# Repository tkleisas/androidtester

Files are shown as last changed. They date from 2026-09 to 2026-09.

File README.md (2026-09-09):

# AndroidTester

An **open-hardware robot that physically tests Android phones and tablets**. A
gantry places the device on a fixture and executes automated scenarios against
it with **real touch and real buttons** — the inputs a user (or a certification
lab) produces, not the inputs a debug bridge injects.

Everything is 3D-printable mechanics, commodity open electronics (Raspberry Pi +
Klipper, the 3D-printer firmware), and a Python framework that turns YAML
scenarios into motion + vision actions.

## Why physical, when ADB exists?

ADB/UI Automator can drive an app, but they can't:

- inject a **capacitive touch event the touchscreen controller actually felt**
  (edge rejection, glove/wet-finger behavior, screen-protector sensitivity),
- press the **physical power/volume buttons**,
- verify behavior with the device in its shipping state.

**Everything is physical.** Input is a real finger and real button presses;
verification is the **camera** — OCR and image checks on the screen as a user
would see it. Fully black-box: works on production builds, no USB debugging, no
agent on the device. The acceptance rule: *a scenario must pass with the
device's USB port unplugged.*

## The machine

- **CoreXY gantry** (3D-printer kinematics) moves a toolhead over the deck.
- **Tool-Z elevator** adapts the tools to device thickness and button height.
- **Finger tool** with a conductive tip taps, swipes, and long-presses the
  touchscreen; small servo plungers in the nest press recessed side buttons.
- **Cameras** (overhead + toolhead) register the deck and read the screen:
  ArUco homography, perspective rectification, OCR.
- **Klipper on a Raspberry Pi** drives motion; the Python framework talks to it
  over Moonraker and never issues raw moves below a safety clearance plane.

The toolhead is modular by design — the finger is the first tool, not the
only one the deck can carry.

## Hardware

The machine is a published open-hardware design (M0):

- **[docs/01-mechanical.md](docs/01-mechanical.md)** — 2020 frame, CoreXY
  layout, tool-Z elevator, finger/button tools, device nest; rail-length and
  tap-force arithmetic.
- **[docs/02-electronics.md](docs/02-electronics.md)** — BTT SKR Pico
  (RP2040) + Raspberry Pi, full pin map, power budget, power-cut E-stop.
- **[docs/03-bom.md](docs/03-bom.md)** — complete BOM, ≈ €420.
- **[cad/openscad/](cad/openscad/)** — parametric printable parts
  (`00_config.scad` holds every shared dimension), STLs in `cad/stl/`,
  previews in `docs/img/` (regenerate with
  `cad/openscad/render_previews.ps1`).
- **[firmware/klipper/androidtester.cfg](firmware/klipper/androidtester.cfg)** —
  the Klipper machine config: CoreXY X/Y, tool-Z as a `manual_stepper`, three
  servos, and the macro contract below.

Key numbers: 400 × 300 mm deck (= X/Y travel), 60 mm tool-Z, 40 mm clearance
plane, 1.5–6 N tap force from the finger's spring, X rail 500 mm / Y 2×400 mm
/ Z 150 mm (travel + carriage + margins — the arithmetic is in the docs and
checked by `tests/test_design_package.py`).

## The framework

YAML scenarios become motion + vision steps with per-step timeouts, artifact
capture, and JSON/JUnit reports:

```yaml
# scenarios/smoke_wake_unlock.yaml (excerpt)
pre:
  - camera.calibrate: { rms_below_mm: 0.5 }  # ArUco deck markers -> px/deck-mm
steps:
  - button.press: { key: power }        # servo plunger on the side button
  - touch.swipe: { from: [50%, 90%], to: [50%, 20%] }
  - touch.enter_pin: { pin_env: DEVICE_PIN_1 }   # secrets from env, never the repo
  - screen.wait_for: { text: "Home", timeout_s: 10 }
```

- **Device profiles** (`devices/*.yaml`): device class (phone/tablet), screen
  polygon, physical-button map, launcher layout, per-model quirks. New device =
  new YAML, not new code.
- **Actions**: `camera.calibrate`, `touch.tap/swipe/long_press/enter_pin`,
  `button.press`, `screen.wait_for/assert_text/assert_image`.
- **Example scenarios**: `smoke_wake_unlock` (power on, swipe, PIN by touch,
  home screen by OCR), `app_regression` (golden-path tap flow with OCR
  assertions), `tablet_rotation` (landscape/portrait UI checks across
  orientations).

## Digital twin

[steropes](https://github.com/tkleisas/steropes) — a 3D physics-based digital
twin for robotic test hardware — is the development companion: the machine's
motion, cameras, and device screen are simulated so the framework and vision
pipeline run before (and without) hardware.

### Run against the Steropes twin

With a steropes checkout on the same machine, the whole framework runs
against the physics simulation with **zero code changes** — only a config.
Terminal 1 (from the steropes checkout):

```
python -m steropes.server --profile profiles/android_phone_v1.yaml --port 7125
```

Terminal 2 (from this repo):

```
DEVICE_PIN_1=1337 .venv/Scripts/python -m androidtester.scenario \
    scenarios/smoke_wake_unlock.yaml --config harness.twin.yaml
```

(`1337` is the simulated DUT's PIN from the twin's own profile — no real
secret involved.) This proves the unmodified framework — motion client,
Klipper macro contract, ArUco deck calibration, and OCR vision checks —
works against a physically simulated machine over real HTTP: every tap is
physics, every verification is a real camera frame. `harness.twin.yaml` is
the stock config with only the Moonraker URL and the overhead camera pointed
at the twin's MJPEG stream.

The same flow also runs as an env-gated integration test that spawns the
twin itself on an ephemeral port:

```
STEROPES_ROOT=/c/projects/steropes .venv/Scripts/python -m pytest tests/test_twin_integration.py
```

## Roadmap

- **M0 — Machine design package** ✅: parametric OpenSCAD parts
  (`cad/openscad/`, previews in `docs/img/`), full Klipper config for a BTT
  SKR Pico rig, electronics and BOM docs (≈ €420). See
  [Hardware](#hardware). Proof:
  ```
  .venv/Scripts/python -m pytest tests/test_design_package.py   # consistency
  powershell -ExecutionPolicy Bypass -File cad/openscad/render_previews.ps1
  ```
- **M1 — Framework** ✅: motion client (Moonraker HTTP + strict `wait_idle`),
  YAML scenario engine with JSON/JUnit reports, vision pipeline (rectification,
  pluggable OCR + template fallback), Klipper macro contract, example device
  profiles and scenarios. Proof:
  ```
  .venv/Scripts/python -m pytest                       # 55 tests
  .venv/Scripts/python -m androidtester.scenario \
      scenarios/smoke_wake_unlock.yaml --dry-run        # no hardware needed
  ```
- **M2 — Camera deck registration** ✅: ArUco markers on the deck, normalized-DLT
  px↔deck-mm homography with RMS gating, `camera.calibrate` scenario step,
  OpenCV + synthetic cameras, fraction-coordinate taps. Proof:
  ```
  .venv/Scripts/python -m pytest                       # 80 tests
  .venv/Scripts/python -m androidtester.calib --device example_phone
      # synthetic deck: per-marker detection + RMS, saves an annotated frame
  ```
- **M3 — Device nest + profiles**: adjustable clamps for phones through tablets,
  side-button pressers, first device YAMLs.
- **M4 — Twin parity** ✅: steropes serves a Moonraker-compatible HTTP API
  and camera streams in front of the physics sim; the unmodified framework
  passes `smoke_wake_unlock` against it. Proof: the two-terminal recipe in
  [Run against the Steropes twin](#run-against-the-steropes-twin) above, or
  ```
  STEROPES_ROOT=/c/projects/steropes .venv/Scripts/python -m pytest  # twin integration tests
  ```

## Status

M0, M1, M2, and M4 done: the machine design package (CAD, Klipper config,
electronics, BOM — see [Hardware](#hardware)), the framework (motion client,
scenario engine, vision pipeline, reports, Klipper macro contract), camera
deck registration (ArUco homography, synthetic camera, calibration CLI), and
twin parity (the unmodified framework passing `smoke_wake_unlock` against the
steropes physics sim over HTTP) are implemented and tested — run them with no
hardware via the proof commands in the roadmap. Next: M3 (device nest +
profiles on real hardware).

## License

[MIT](LICENSE) — do what you want, attribution appreciated.

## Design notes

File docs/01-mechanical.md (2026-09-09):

# 01 — Mechanical design

The machine is a CoreXY gantry over a **400 × 300 mm deck**, built from 2020
extrusion, MGN linear rails, and printed parts (`cad/openscad/`, all
parametric — every dimension lives in `00_config.scad`). A tool-Z elevator
raises/lowers the tools; a servo-deployed conductive finger does touch input;
two servo plungers in the nest press side buttons.

## Frame

Base frame 500 × 400 mm (2020 extrusion, printed 3-way `corner_bracket`s),
four 200 mm posts, two 400 mm side beams carrying the Y rails, one 500 mm
gantry beam carrying the X rail, one 400 mm camera post at the rear. The deck
plate (400 × 300 × 4 mm aluminium) bolts to the base frame with an M4 hole
grid for the nest hardware.

Cut plan (2020, in mm): 2×500 + 2×400 base, 4×200 posts, 2×400 side beams,
1×500 gantry beam, 1×400 camera post → **4.3 m total → buy 5× 1 m** (0.7 m
spare for jigs and mistakes).

## Motion layout

- **X/Y: CoreXY.** Two NEMA17s with GT2 20T pulleys (2.0 mm pitch × 20 teeth
  = **40.0 mm/rev** `rotation_distance`), belt routed around 6 idlers, both
  belt ends terminate in `belt_clamp` wedges on the `toolhead_plate`. X rides
  a single MGN12H rail on the gantry beam; the beam ends ride two MGN12H Y
  rails on the side beams.
- **Tool-Z: elevator.** NEMA17 + T8 lead screw (2 mm pitch × 4 starts =
  **8 mm/rev**), 5→8 mm coupler, MGN9H rail (150 mm) guiding the tool lift.
  Driven as a Klipper `manual_stepper` — no G-code path can move Z; only the
  macro contract touches it. Homes **up** against a microswitch at the top of
  travel, away from the deck.

### Rail lengths (the arithmetic)

Rail ≥ travel + carriage length + 2 × end margin (10 mm: endstop trigger +
belt/idler clearance at each end). Same numbers in `00_config.scad`, enforced
by `tests/test_design_package.py`:

| Axis | Travel | Carriage | Margins | Min rail | Stock rail |
|---|---|---|---|---|---|
| X | 400 | 45 (MGN12H) | 2×10 | **465** | **500** |
| Y | 300 | 45 (MGN12H) | 2×10 | **365** | **400** (×2) |
| Z | 60 | 40 (MGN9H)  | 2×10 | **120** | **150** |

Travels equal the deck size (`position_max` in the cfg == `deck_width_mm` /
`deck_height_mm` in `androidtester/config.py`), so the finger reaches every
deck point including the ArUco corner markers.

## Tools

- **Finger** (`finger_module.scad`): a spring-loaded plunger in a printed
  body — Ø8 mm conductive stylus tip (M3 grub screw), Ø6 mm shaft in a guide
  bore, Ø8 × 25 mm compression spring in a top pocket retained by the
  toolhead plate. A deploy servo (`finger_deploy`, MG90S) swings the body
  between stow (clear of the nest) and working (vertical) positions.
- **Button plungers** (`button_plunger.scad`): two nest-mounted MG90S servos
  (`plunger_0`, `plunger_1`) driving Ø6 mm pins through guide bores into the
  device's side buttons. Slotted bases give 10 mm of edge-distance adjustment
  on the deck grid.

### Tap force budget

Target contact force: **1.5–6 N** (below the force that slides a device in
rubber-padded stops, above the touchscreen's registration threshold).

The Z axis does not control force — the **spring** does. Spring rate
k ≈ 0.5 N/mm (Ø8 × 25 mm compression spring, typical assortment value). The
framework sets `touch_z` so the tip meets the glass with the spring already
compressed ~3 mm:

- 3 mm compression → 1.5 N (light tap)
- up to 12 mm → 6 N (firm press / worn screen protector)

Z positioning resolution (8 mm/rev ÷ 200 full steps ÷ 16 µsteps =
**2.5 µm/µstep**) sets the compression to within 0.05 mm (≈0.03 N) — well
below the ~0.1 N system repeatability from homing and spring tolerances. The
15 mm plunger stroke absorbs device-thickness tolerance; the servo stow keeps
the tip off the deck during device swaps.

## Device nest

`device_nest.scad`: two fixed `corner_stop` L-references + two sliding
`side_clamp`s (30 mm slots, M5 thumb tabs) on the deck's M4 grid. Holds
devices from phones to ~11" tablets (≤ 280 × 200 mm). All nest hardware is
≤ 8 mm tall — below the screen, out of the overhead camera's view of the
glass, and outside the 40 mm ArUco keep-out zones at the deck corners
(`NEST_CLEAR`; markers sit one marker-width, 20 mm, in from each corner — see
`config.py deck_marker_map`).

## Cameras

- **Overhead**: USB webcam on the 400 mm rear post (`overhead_clamp`). A
  ~60°-FoV webcam at 400 mm covers ~460 mm across — the full 400 mm deck with
  margin. Used for ArUco deck registration and screen OCR.
- **Toolhead**: USB webcam under the gantry plate (`toolcam_bracket`), for
  close-up verification of taps and button states.

## Printed parts

| File | Parts | Notes |
|---|---|---|
| `frame_brackets.scad` | corner_bracket, motor_plate, idler_mount | ×4 corners, ×3 motor (X/Y/tool-Z), ×6 idler |
| `gantry_carriage.scad` | toolhead_plate, belt_clamp | plate ×1, clamp ×2 |
| `finger_module.scad` | finger_body, deploy_arm | |
| `button_plunger.scad` | plunger_base, plunger_pin | ×2 of each |
| `device_nest.scad` | corner_stop, side_clamp | ×2 of each |
| `camera_mounts.scad` | overhead_clamp, toolcam_bracket | |

Print in PETG, 4 perimeters, 40% infill. Previews in `docs/img/`, STLs in
`cad/stl/` — regenerate both with
`powershell -ExecutionPolicy Bypass -File cad/openscad/render_previews.ps1`.

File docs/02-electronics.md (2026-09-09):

# 02 — Electronics

## Controller: BIGTREETECH SKR Pico v1.0

Choice: **SKR Pico (RP2040)** running Klipper, hosted by a Raspberry Pi over
USB. Rationale:

- 4 TMC driver sockets for a machine that needs exactly **3 steppers**
  (CoreXY A/B + tool-Z) — no wasted board, no external drivers.
- Native Klipper support, RP2040 PWM on any GPIO (needed for 3 servos).
- Cheap (~€35), widely stocked, fully documented pinout; the Voron 0
  ecosystem proves the pin map.
- 24 V in, on-board 5 V — though we still power the Pi separately (see
  E-stop below).

The Raspberry Pi (4B, 2 GB) runs Klipper/Moonraker + the Python framework
and talks to the Pico over USB (`/dev/serial/by-id/...`, set in
`firmware/klipper/androidtester.cfg`).

## Pin map (matches `androidtester.cfg` exactly)

| Function | Pins | SKR Pico port |
|---|---|---|
| X step / dir / en | gpio11 / gpio10 / !gpio12 | X driver socket |
| X endstop | ^gpio4 | X-STOP |
| Y step / dir / en | gpio6 / gpio5 / !gpio7 | Y driver socket |
| Y endstop | ^gpio3 | Y-STOP |
| tool-Z step / dir / en | gpio19 / gpio28 / !gpio2 | Z driver socket |
| tool-Z endstop (top) | ^gpio25 | Z-STOP |
| TMC2209 UART (all) | gpio9 RX / gpio8 TX | shared; addresses X=0, Z=1, Y=2 (socket MS jumpers) |
| plunger_0 servo | gpio29 | SERVO port |
| plunger_1 servo | gpio14 | E0 socket STEP pin |
| finger_deploy servo | gpio13 | E0 socket DIR pin |
| placeholder stepper_z | gpio16 / gpio22 / !gpio15, endstop ^gpio26 | FSC / PROBE / E0-EN / THB — **nothing attached** |

Two notes:

- **E0 socket stays empty.** The machine has no extruder; its STEP/DIR pins
  are repurposed as servo signals #2 and #3. Servo 5 V/GND comes from the
  servo buck (below), not from the board.
- **Placeholder `stepper_z`.** Klipper's `corexy` kinematics loads x/y/z
  rails unconditionally, so a dummy Z rail sits on free pins and is never
  homed or moved (`HOME_ALL` does `G28 X Y` only). The real tool elevator is
  `[manual_stepper tool_z]`, commanded exclusively via `MANUAL_STEPPER` from
  the macro contract — no G-code path can crash Z into the deck.

## Power budget

| Rail | Load | Worst case | Supply |
|---|---|---|---|
| 24 V motion | 2× CoreXY NEMA17 @0.8 A RMS ≈ 2×15 W + tool-Z ≈ 10 W + board logic ≈ 5 W | ≈ 45 W | Meanwell LRS-150-24 (150 W) — >3× headroom |
| 5 V servo rail | 3× MG90S, stall 0.7 A each | ≈ 2.1 A ≈ 11 W | LM2596 buck 5 V/3 A from 24 V |
| 5 V Pi | Pi 4B + 2 USB webcams | ≈ 15 W | official 5 V/3 A USB-C supply |

## E-stop: power-cut, not firmware

A **2-pole NC mushroom** sits in series with the 24 V feed:

- pole 1 → SKR Pico VIN (kills steppers and board),
- pole 2 → servo buck input (kills the servo rail).

Motion power dies even if Klipper hangs; the Pi and cameras stay alive on
their own supply so the framework can capture the post-mortem frame and
report cleanly. This is why the Pi is *not* powered from the Pico's GPIO 5 V.
`M112` remains as the software layer on top.

## Wiring notes

- Endstops: lever microswitches, COM→G, NC→signal, `^` pull-ups as in the
  cfg. X/Y switches at the min ends; tool-Z switch at the **top** (home up,
  away from the deck).
- TMC2209s: set the MS jumpers for UART addresses X=0, Z=1, Y=2; one shared
  UART (gpio9/gpio8). Start at the cfg currents (0.8 A X/Y, 0.6 A tool-Z).
- Servos: signal wires from gpio29 (SERVO port) and the E0 STEP/DIR pads;
  5 V/GND from the buck. **Common ground** between buck output and SKR Pico
  GND is mandatory (the buck input shares 24 V GND with the board, which
  satisfies this).
- Toolhead loom (tool-Z motor, deploy servo, toolcam USB) in the 10×15 mm
  drag chain; leave USB-C camera leads strain-relieved at both ends.
- Bed/heater ports (gpio21/gpio23), fans (gpio17/18/20) and TH0 (gpio27) are
  unused; leave them unconfigured.

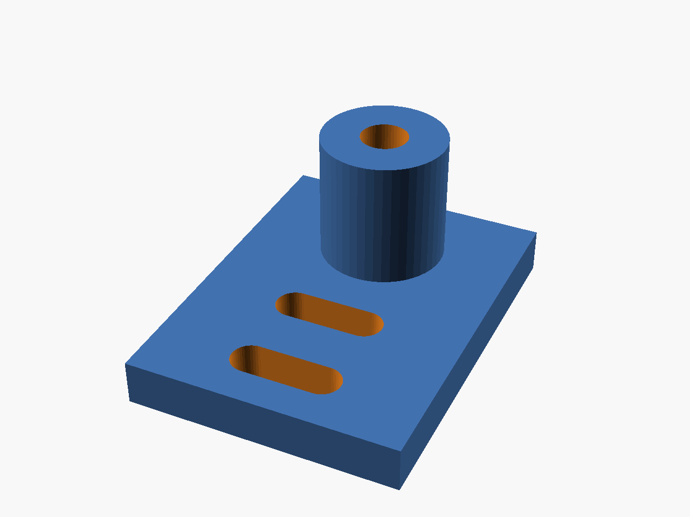
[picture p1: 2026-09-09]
docs/img/idler_mount.png

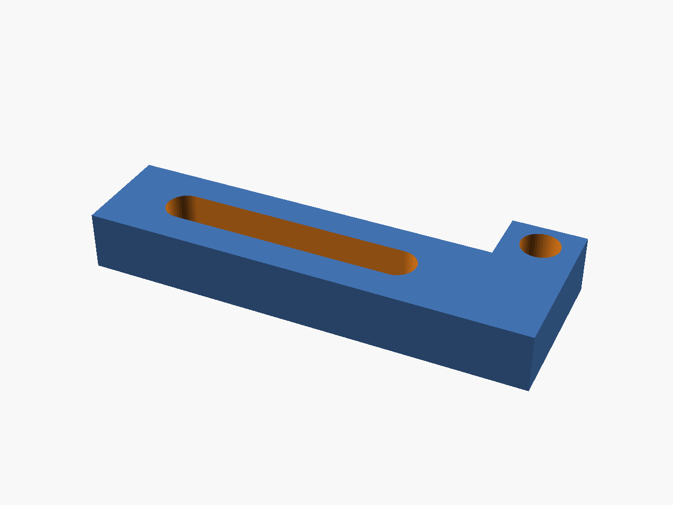
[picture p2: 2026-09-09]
docs/img/side_clamp.png

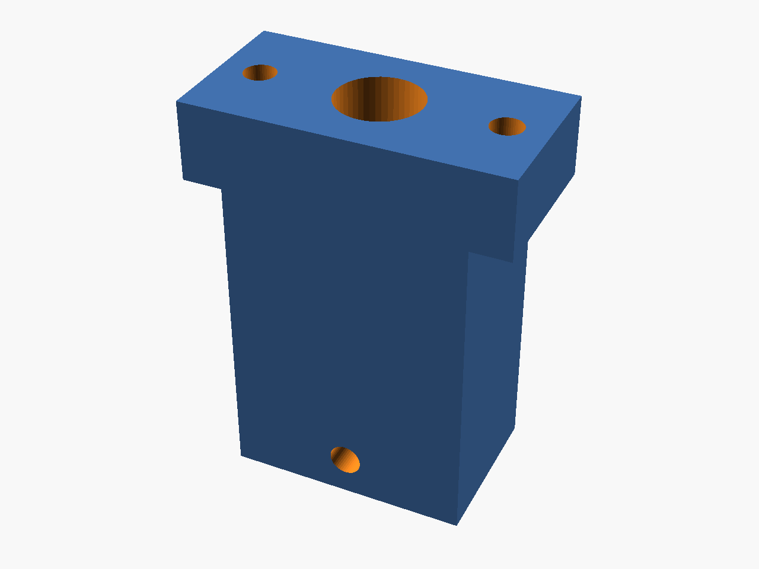
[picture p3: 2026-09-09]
docs/img/finger_body.png

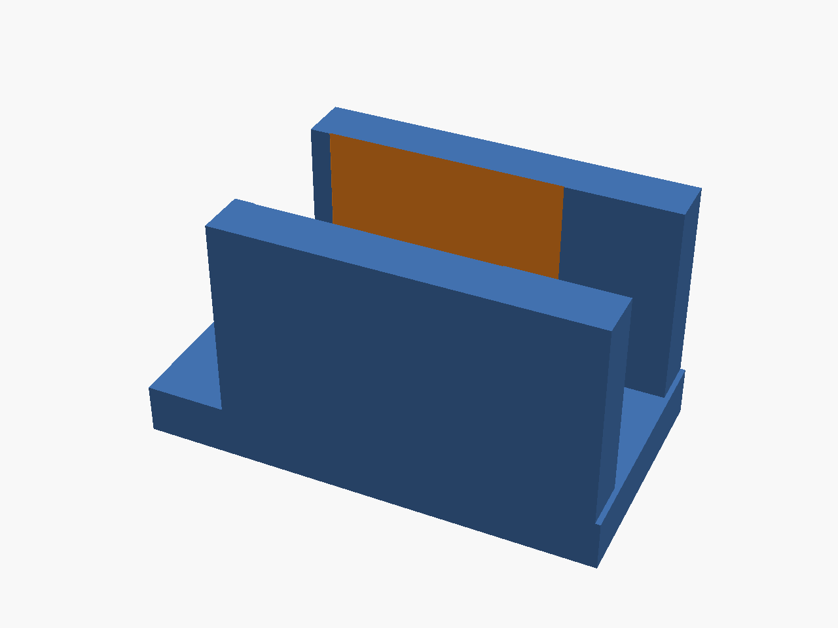
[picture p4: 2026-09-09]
docs/img/plunger_base.png

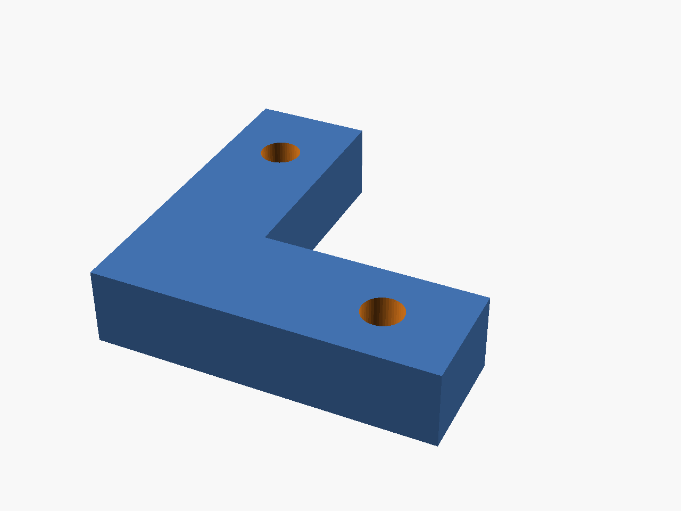
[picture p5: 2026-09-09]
docs/img/corner_stop.png

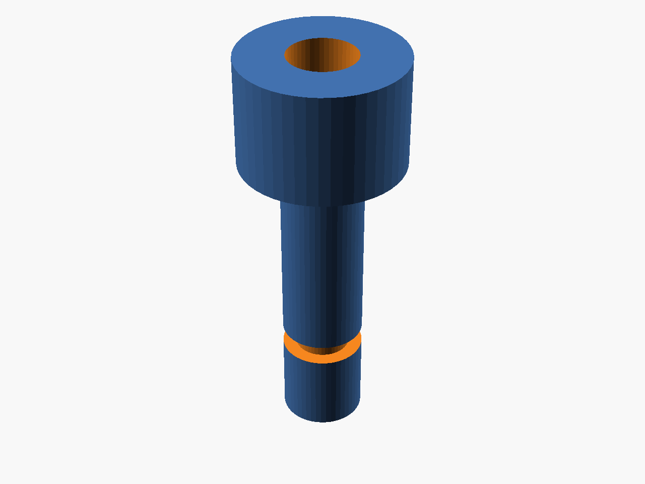
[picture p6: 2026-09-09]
docs/img/plunger_pin.png

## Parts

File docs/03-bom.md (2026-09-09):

# 03 — Bill of materials

Rough 2025 street prices (EUR, EU shops/AliExpress average), quantities match
`docs/01-mechanical.md` and `docs/02-electronics.md`. The table's arithmetic
is checked by `tests/test_design_package.py` (per-row qty × unit = line, and
the rows sum to the stated total).

| # | Item | Spec / purpose | Qty | Unit € | Line € |
|---|---|---|-----|---|---|
| 1 | 2020 aluminium extrusion, 1 m | frame 500×400, posts, gantry beam, camera post (4.3 m cut plan) | 5 | 6.00 | 30.00 |
| 2 | 2020 corner bracket + T-nut/screw kit | frame joinery | 1 | 15.00 | 15.00 |
| 3 | MGN12H linear rail 500 mm + carriage | X axis (min 465: 400 travel + 45 carriage + 2×10 margin) | 1 | 18.00 | 18.00 |
| 4 | MGN12H linear rail 400 mm + carriage | Y axis pair (min 365) | 2 | 15.00 | 30.00 |
| 5 | MGN9H linear rail 150 mm + carriage | tool-Z (min 120) | 1 | 9.00 | 9.00 |
| 6 | NEMA17 stepper, 40 mm, 1.5 A | CoreXY A/B + tool-Z = 3 steppers | 3 | 12.00 | 36.00 |
| 7 | GT2 20T drive pulley, 5 mm bore | CoreXY A/B motors (tool-Z is lead-screw driven) | 2 | 1.50 | 3.00 |
| 8 | GT2 20T idler pulley, 5 mm bore | CoreXY belt returns | 6 | 1.50 | 9.00 |
| 9 | GT2 open belt, 6 mm, 5 m roll | CoreXY loop (~2 m) + spare | 1 | 8.00 | 8.00 |
| 10 | T8 lead screw, 8 mm lead, 150 mm + nut | tool-Z elevator (8 mm/rev) | 1 | 8.00 | 8.00 |
| 11 | Flexible shaft coupler 5→8 mm | tool-Z motor to lead screw | 1 | 3.00 | 3.00 |
| 12 | BIGTREETECH SKR Pico v1.0 | motion controller (RP2040, Klipper) | 1 | 35.00 | 35.00 |
| 13 | TMC2209 stepper driver | X, Y, tool-Z = 3 drivers | 3 | 6.00 | 18.00 |
| 14 | Raspberry Pi 4B, 2 GB | Klipper/Moonraker host + framework | 1 | 50.00 | 50.00 |
| 15 | microSD card 32 GB | Pi system | 1 | 8.00 | 8.00 |
| 16 | Endstop microswitch with lever | X-min, Y-min, tool-Z top | 3 | 1.00 | 3.00 |
| 17 | MG90S servo (metal gear) | plunger_0, plunger_1, finger_deploy | 3 | 4.00 | 12.00 |
| 18 | LM2596 buck module, 5 V/3 A | servo rail from 24 V | 1 | 3.00 | 3.00 |
| 19 | Meanwell LRS-150-24 PSU | 24 V motion + servo buck input | 1 | 25.00 | 25.00 |
| 20 | E-stop mushroom, 22 mm, 2-pole NC | power cut (motion + servo rails) | 1 | 6.00 | 6.00 |
| 21 | USB webcam 1080p | overhead + toolhead cameras | 2 | 12.00 | 24.00 |
| 22 | Conductive stylus tips, Ø8 mm | finger tool, consumable | 5 | 1.00 | 5.00 |
| 23 | Compression spring assortment, Ø8×25 | finger plunger, k ≈ 0.5 N/mm | 1 | 5.00 | 5.00 |
| 24 | Deck plate 400×300×4 mm, aluminium | M4 grid drilled for nest hardware | 1 | 12.00 | 12.00 |
| 25 | Wire/ferrule/JST-XH/Dupont kit | all cabling | 1 | 15.00 | 15.00 |
| 26 | PETG filament, ~0.5 kg | printed parts (0.4 kg estimated) | 1 | 10.00 | 10.00 |
| 27 | M3/M4/M5 bolt & nut kit | assembly | 1 | 10.00 | 10.00 |
| 28 | Cable drag chain 10×15 mm, 1 m | toolhead loom | 1 | 8.00 | 8.00 |

**Total: ≈ €418.00** (the exact sum of the Line € column; "≈" because unit
prices are rough). Not included: shipping, a USB-C cable for the Pi↔Pico
link, and the Android device under test.

## Sourcing notes

- Rails: "MGN12H" = the long carriage; vendor block-hole spacing varies
  (nominal M3 on 20×20 mm) — check the delivered blocks before bolting down
  `toolhead_plate`.
- Any SG90/MG90S-class 9 g servo fits the pockets; metal-gear MG90S survives
  plunger duty longer.
- The SKR Pico clones vary in TMC UART jumper labelling — the addresses
  (X=0, Z=1, Y=2) are what the cfg assumes; verify with `DUMP_TMC`.

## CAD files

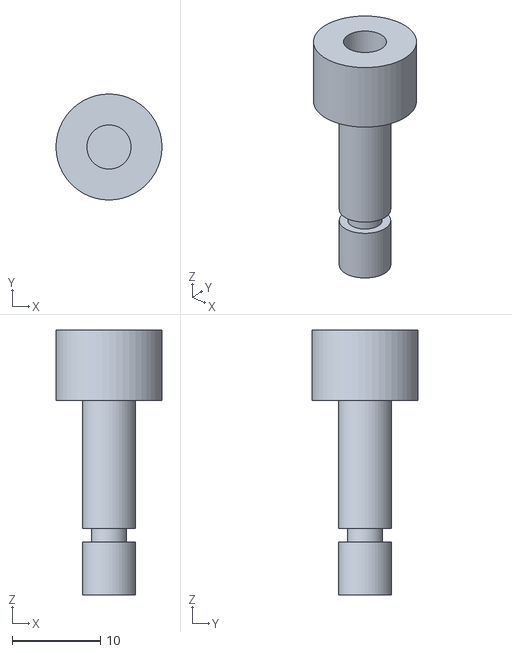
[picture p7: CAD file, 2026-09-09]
cad/stl/plunger_pin.stl
12.0 x 12.0 x 30.0

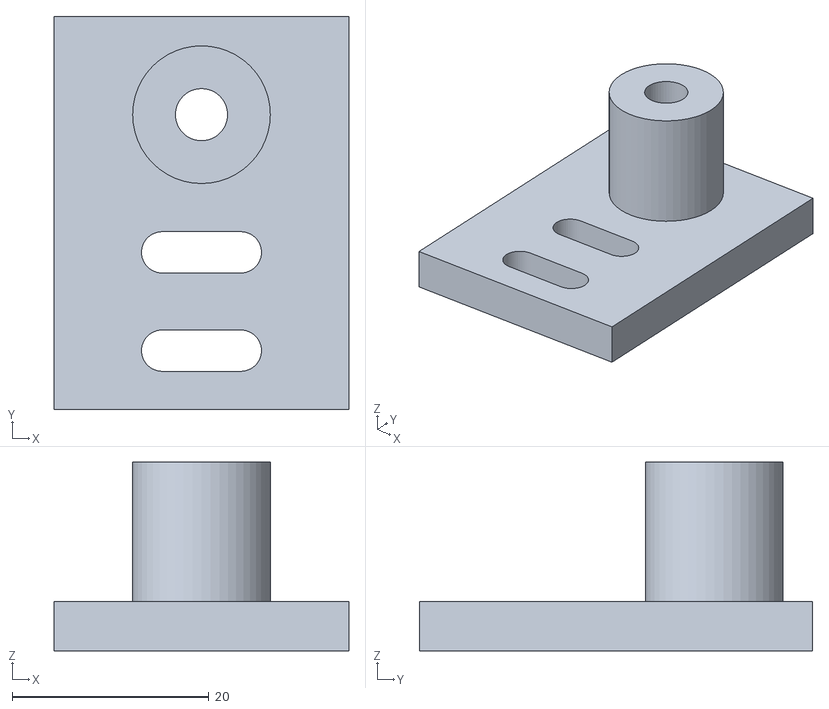
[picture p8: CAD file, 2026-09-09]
cad/stl/idler_mount.stl
30.0 x 40.0 x 19.2

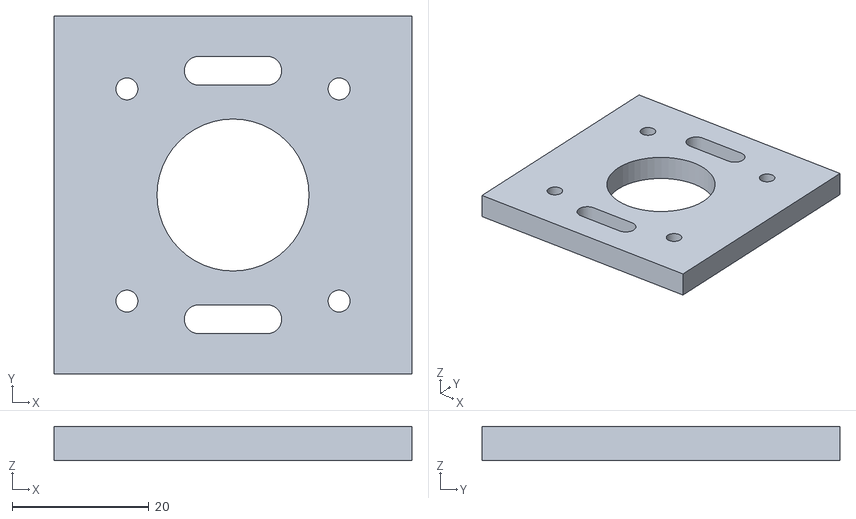
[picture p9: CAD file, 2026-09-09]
cad/stl/motor_plate.stl
52.3 x 52.3 x 5.00

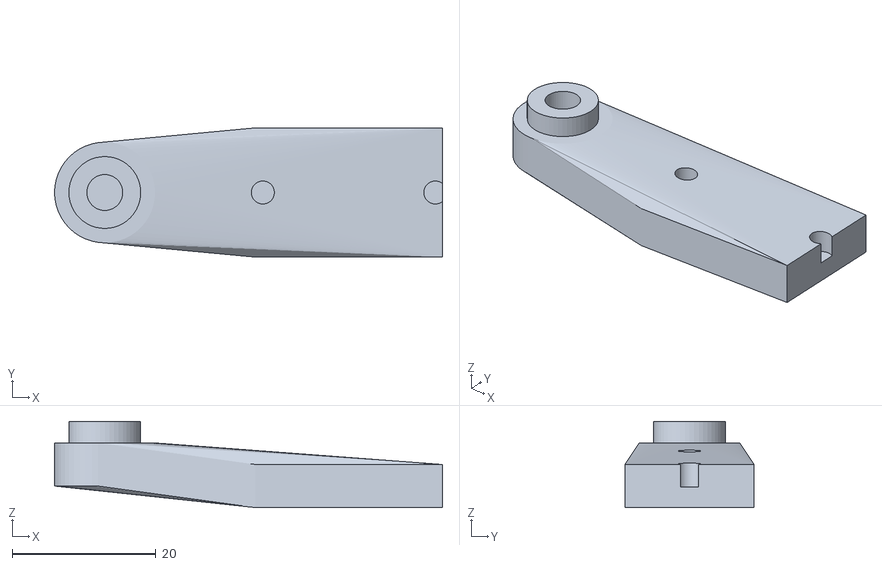
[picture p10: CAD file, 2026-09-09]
cad/stl/deploy_arm.stl
54.0 x 18.0 x 12.0

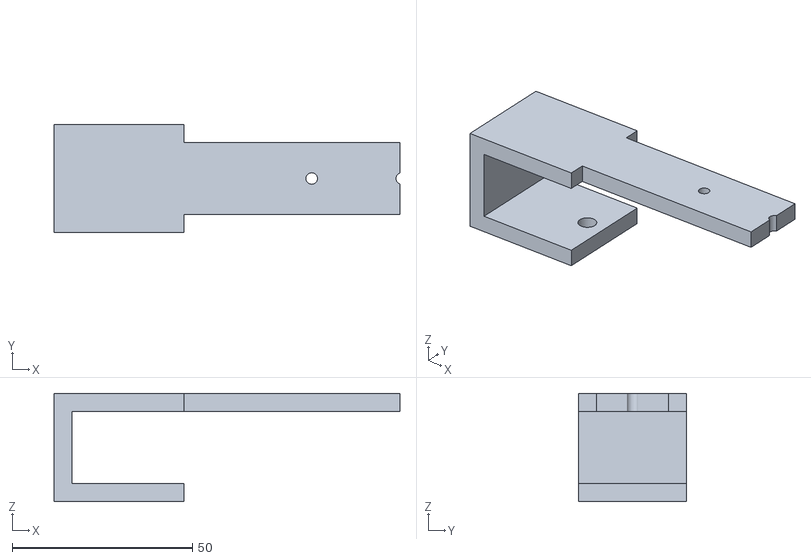
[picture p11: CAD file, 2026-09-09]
cad/stl/overhead_clamp.stl
96.0 x 30.0 x 30.0

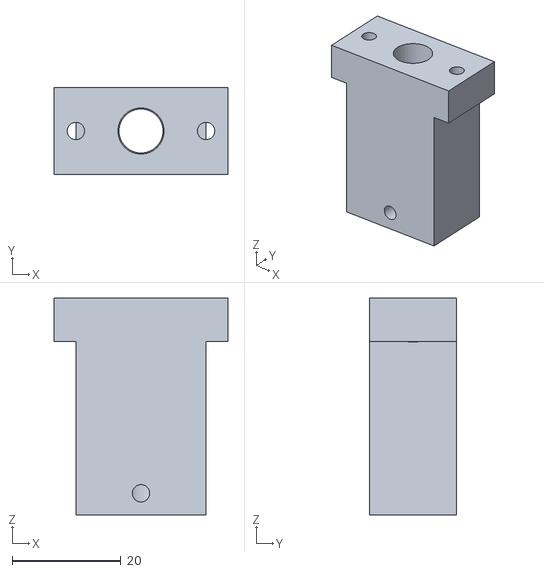
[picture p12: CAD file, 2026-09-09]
cad/stl/finger_body.stl
32.0 x 16.0 x 40.0

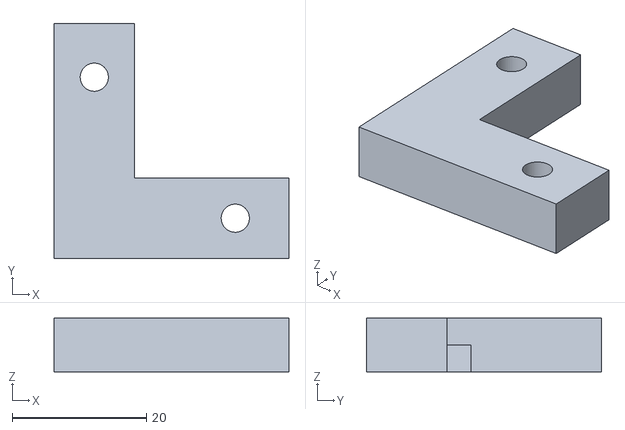
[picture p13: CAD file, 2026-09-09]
cad/stl/corner_stop.stl
35.0 x 35.0 x 8.00

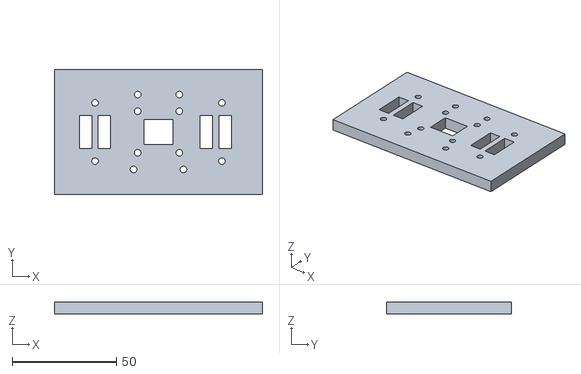
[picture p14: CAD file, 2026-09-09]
cad/stl/toolhead_plate.stl
100.0 x 60.0 x 6.00

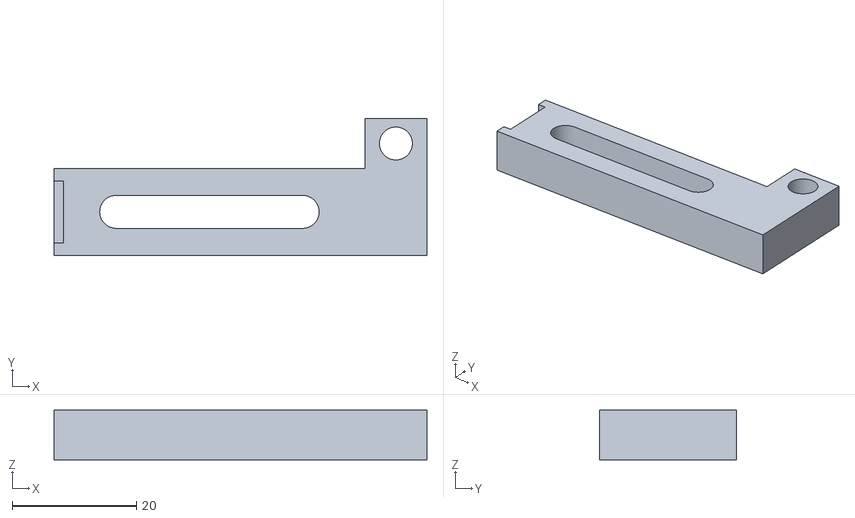
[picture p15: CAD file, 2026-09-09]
cad/stl/side_clamp.stl
60.0 x 22.0 x 8.00

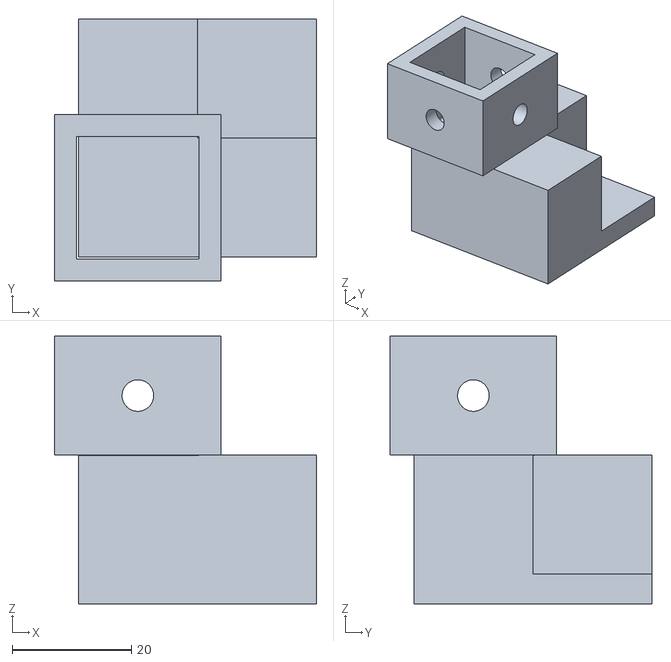
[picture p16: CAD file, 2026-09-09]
cad/stl/corner_bracket.stl
44.0 x 44.0 x 45.0

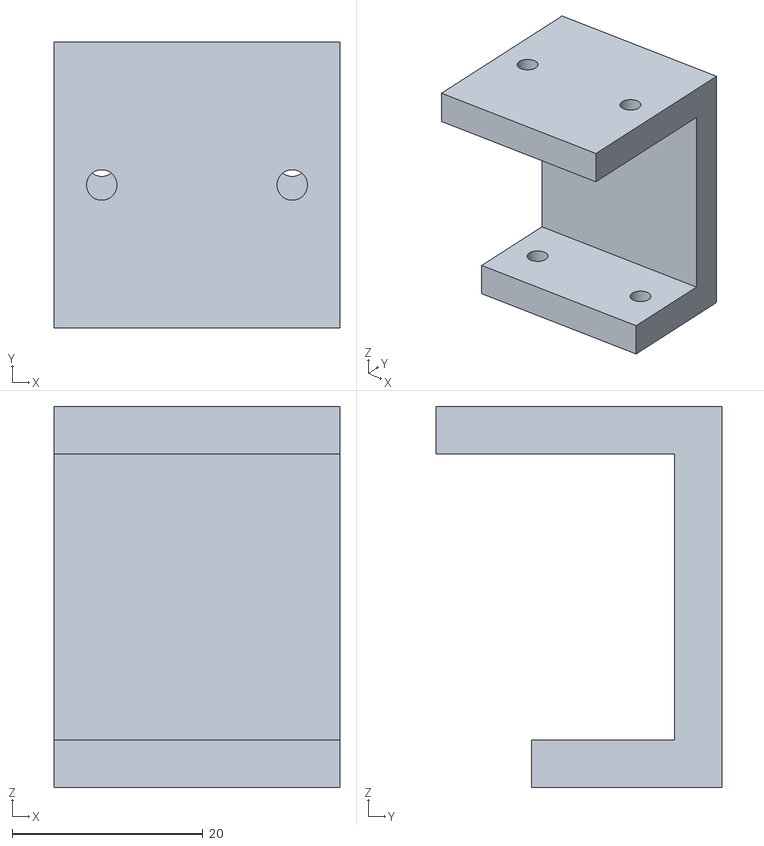
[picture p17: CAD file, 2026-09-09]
cad/stl/toolcam_bracket.stl
30.0 x 30.0 x 40.0

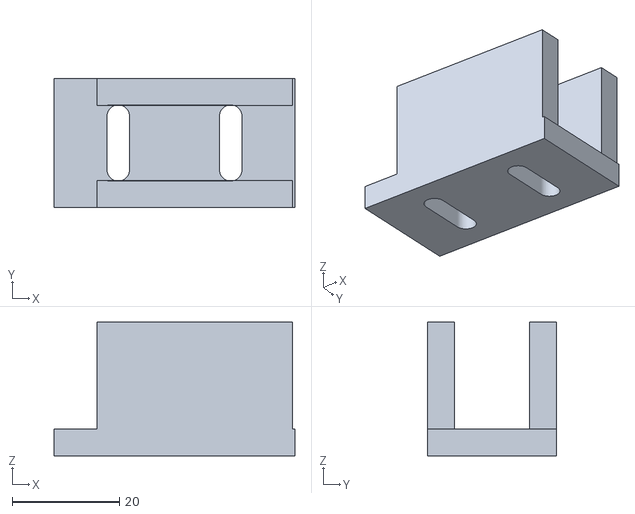
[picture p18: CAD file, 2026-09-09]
cad/stl/plunger_base.stl
45.0 x 24.0 x 25.0

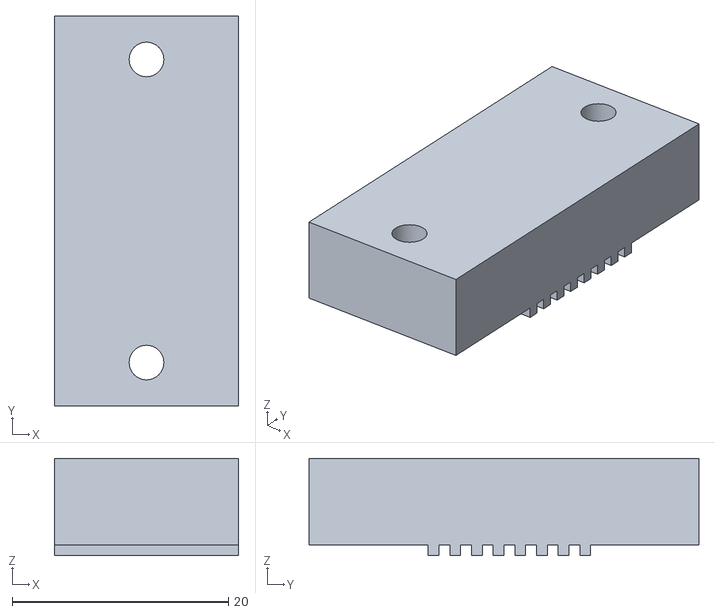
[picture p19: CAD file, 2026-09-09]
cad/stl/belt_clamp.stl
17.0 x 36.0 x 9.00

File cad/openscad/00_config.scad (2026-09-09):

// 00_config.scad — shared dimensions for the AndroidTester machine, in mm.
//
// These constants are the single source for every part in cad/openscad/.
// They are cross-checked by tests/test_design_package.py against
// androidtester/config.py (deck size, clearance planes) and
// firmware/klipper/androidtester.cfg (position_max) — change them together.

// -- deck and travels -------------------------------------------------------
// Deck == reachable XY (cfg position_max == config.py deck defaults).
DECK_W   = 400;          // deck X, config.py deck_width_mm, stepper_x position_max
DECK_D   = 300;          // deck Y, config.py deck_height_mm, stepper_y position_max
X_TRAVEL = 400;          // == DECK_W
Y_TRAVEL = 300;          // == DECK_D
Z_TRAVEL = 60;           // tool-Z elevator travel (manual_stepper tool_z)
TRAVEL_Z = 40;           // clearance plane, config.py travel_z_mm
TOUCH_Z  = 5;            // finger-tip contact plane, config.py touch_z_mm

// -- linear rails -------------------------------------------------------------
// X rail: must span the full X travel plus the carriage plus end margins:
//   X_TRAVEL (400) + X_CARRIAGE_LEN (45) + 2*END_MARGIN (10) = 465 mm min
//   -> RAIL_X_LEN = 500 (next stock MGN12 length, 35 mm of setup slack).
// Y rails (x2, carry the gantry beam):
//   Y_TRAVEL (300) + X_CARRIAGE_LEN (45) + 2*END_MARGIN (10) = 365 mm min
//   -> RAIL_Y_LEN = 400.
// Z rail (tool elevator, MGN9):
//   Z_TRAVEL (60) + Z_CARRIAGE_LEN (40) + 2*END_MARGIN (10) = 120 mm min
//   -> RAIL_Z_LEN = 150.
RAIL_X_LEN = 500;
RAIL_Y_LEN = 400;
RAIL_Z_LEN = 150;
X_CARRIAGE_LEN = 45;     // MGN12H block, 27 x 45.4 mm (nominal — verify rail vendor)
Z_CARRIAGE_LEN = 40;     // MGN9H block, 20 x 38.9 mm (nominal — verify rail vendor)
END_MARGIN   = 10;       // endstop trigger + belt/idler clearance at each rail end
RAIL12_W = 12;           // MGN12 rail width / height
RAIL12_H = 8;
RAIL9_W  = 9;            // MGN9 rail width / height
RAIL9_H  = 6.5;

// -- frame --------------------------------------------------------------------
EXT = 20;                // 2020 aluminium extrusion (6 mm slot)
FRAME_W = DECK_W + 100;  // 500 — gantry beam carries the full X rail (500)
FRAME_D = DECK_D + 100;  // 400 — side beams carry the full Y rails (400)
POST_H  = 200;           // gantry posts above the base frame
CAM_POST_H = 400;        // overhead camera post above the deck

// -- motors / motion hardware ---------------------------------------------------
NEMA_W   = 42.3;         // NEMA17 face
NEMA_HOLE_SP = 31;       // NEMA17 M3 hole spacing
NEMA_BORE  = 22.2;       // NEMA17 pilot bore (clearance)
PULLEY_D = 12.2;         // GT2 20T pulley OD (2 mm pitch x 20 T = 40 mm/rev)
IDLER_D  = 12.2;         // GT2 20T idler OD, 5 mm bore
BELT_W   = 6;            // GT2 belt width
LEAD_D   = 8;            // T8 lead screw (2 mm pitch x 4 starts = 8 mm/rev)

// -- servos (SG90 / MG90S class) -------------------------------------------------
SERVO_W   = 23;          // body across tabs axis
SERVO_D   = 12.5;        // body depth
SERVO_H   = 23;          // body height below the mounting tabs
SERVO_TAB_W = 32.5;      // across the mounting tabs
SERVO_SHAFT_D = 5;       // output shaft / horn boss clearance
SERVO_SHAFT_OFF = 6;     // shaft centre from body end wall

// -- finger tool -----------------------------------------------------------------
FINGER_TIP_D  = 8;       // conductive tip diameter
FINGER_SHAFT_D = 6;      // plunger shaft
SPRING_D  = 8.5;         // compression-spring pocket (Ø8 spring, k ≈ 0.5 N/mm)
FINGER_STROKE = 15;      // spring working stroke (3–12 mm compression -> 1.5–6 N)

// -- fasteners ---------------------------------------------------------------------
M3_CLEAR = 3.2;
M4_CLEAR = 4.2;
M5_CLEAR = 5.3;
M3_HEAD  = 6.0;          // M3 button-head clearance

// -- device nest ---------------------------------------------------------------------
DEVICE_MAX_W = 280;      // phones through ~11" tablets (250 x 170 + case)
DEVICE_MAX_D = 200;
NEST_STOP_H  = 8;        // stop height: below screen, clear of ArUco markers
NEST_CLEAR   = 40;       // keep-out at each deck corner (ArUco marker zone)

$fn = 48;

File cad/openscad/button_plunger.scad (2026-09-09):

// button_plunger.scad — nest-mounted servo plunger for recessed side buttons
// (power / volume). The servo body bolts to a slotted base on the deck plate;
// its horn carries a Ø6 push pin riding in a guide bore, aligned with the
// device edge. Two of these live on the nest (plunger_0 / plunger_1).
//
// Parts (PART selector):
//   plunger_base — servo cradle + deck slots (M4, 15 mm edge-distance travel)
//   plunger_pin  — push pin with horn hub and return-spring groove
//
// Export: openscad -o plunger_base.stl -D 'PART="plunger_base"' button_plunger.scad
include <00_config.scad>

PART = is_undef(_AT_PART) ? "preview" : _AT_PART;  // -D 'PART=...' or a render wrapper overrides

module plunger_base() {
    base_w = 45;
    base_d = 24;
    t = 5;
    cradle_h = 20;
    gap = base_d - 2 * t;   // 14 mm = SERVO_D (12.5) + running clearance
    difference() {
        union() {
            cube([base_w, base_d, t]);
            // cradle walls: servo body drops between them, tabs rest on top
            for (sy = [0, base_d - t])
                translate([8, sy, t]) cube([SERVO_TAB_W + 4, t, cradle_h]);
        }
        // servo well between the walls, open at the top (tabs sit on the walls)
        translate([8 + 2, t - 0.1, t + 4])
            cube([SERVO_W + 0.4, gap + 0.2, cradle_h]);
        // pin guide bore Ø6.2 through both walls at horn height
        translate([8 - 0.1, base_d / 2, t + 12])
            rotate([0, 90, 0]) cylinder(d = 6.2, h = SERVO_TAB_W + 4.2);
        // M4 deck slots, 10 mm of edge-distance adjustment
        for (x = [12, base_w - 12])
            hull()
                for (dy = [-5, 5])
                    translate([x, base_d / 2 + dy, -0.1])
                        cylinder(d = M4_CLEAR, h = t + 0.2);
    }
}

module plunger_pin() {
    pin_l = 30;
    difference() {
        union() {
            cylinder(d = 6, h = pin_l);                       // push pin
            translate([0, 0, pin_l - 8]) cylinder(d = 12, h = 8); // horn hub
        }
        // horn boss bore + M3 screw
        translate([0, 0, pin_l - 8.1]) cylinder(d = SERVO_SHAFT_D, h = 8.2);
        // return-spring groove (Ø1 wire, 2 mm deep, 6 mm from the tip)
        translate([0, 0, 6]) rotate_extrude()
            translate([2, 0, 0]) square([2, 1.5]);
    }
}

// -- preview / selector ---------------------------------------------------------
if (PART == "preview" || PART == "plunger_base")
    plunger_base();
if (PART == "preview")
    translate([55, 15, 0]) plunger_pin();
else if (PART == "plunger_pin")
    plunger_pin();

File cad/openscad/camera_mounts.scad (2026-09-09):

// camera_mounts.scad — machine-vision mounts.
//   overhead_clamp — clamps the rear 2020 post, holds the overhead webcam
//                    CAM_POST_H (400 mm) above the deck centre
//   toolcam_bracket — toolhead camera on the gantry plate's rear M3 pattern
//
// Export: openscad -o overhead_clamp.stl -D 'PART="overhead_clamp"' camera_mounts.scad
include <00_config.scad>

PART = is_undef(_AT_PART) ? "preview" : _AT_PART;  // -D 'PART=...' or a render wrapper overrides

module overhead_clamp() {
    w = EXT + 16;        // wraps the post with two 8 mm cheeks
    t = 5;
    arm = 60;            // camera arm toward the deck centre
    difference() {
        union() {
            // C-clamp around the 2020 post
            cube([w, EXT + 2 * t, t]);                  // jaw bottom
            translate([0, 0, t]) cube([t, EXT + 2 * t, EXT]); // spine
            translate([0, 0, t + EXT]) cube([w, EXT + 2 * t, t]); // jaw top
            // camera arm off the top jaw
            translate([w, t, t + EXT]) cube([arm, EXT, t]);
        }
        // M5 clamp screw pulling the jaws onto the post slots
        translate([w - 6, t + EXT / 2, -0.1]) cylinder(d = M5_CLEAR, h = t + 0.2);
        // webcam plate holes: 2 x M3 on 25 mm spacing at the arm end
        for (sx = [-1, 1])
            translate([w + arm - 12 + sx * 12.5, t + EXT / 2, t + EXT - 0.1])
                cylinder(d = M3_CLEAR, h = t + 0.2);
    }
}

module toolcam_bracket() {
    w = 30;
    t = 5;
    drop = 35;           // camera sits below the plate, lens past the finger
    difference() {
        union() {
            cube([w, w, t]);                             // flange to the plate
            translate([0, w - t, -drop]) cube([w, t, drop + t]); // vertical leg
            translate([0, w - t - 15, -drop]) cube([w, 15, t]); // camera shelf
        }
        // flange holes matching the toolhead plate rear pattern (20 mm)
        for (sx = [-1, 1])
            translate([w / 2 + sx * 10, w / 2, -0.1])
                cylinder(d = M3_CLEAR, h = t + 0.2);
        // camera M3 holes in the shelf
        for (sx = [-1, 1])
            translate([w / 2 + sx * 10, w - t - 7.5, -drop - 0.1])
                cylinder(d = M3_CLEAR, h = t + 0.2);
    }
}

// -- preview / selector ---------------------------------------------------------
if (PART == "preview" || PART == "overhead_clamp")
    overhead_clamp();
if (PART == "preview")
    translate([110, 0, 45]) toolcam_bracket();
else if (PART == "toolcam_bracket")
    toolcam_bracket();

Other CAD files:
cad/openscad/device_nest.scad
cad/openscad/finger_module.scad
cad/openscad/frame_brackets.scad
cad/openscad/gantry_carriage.scad

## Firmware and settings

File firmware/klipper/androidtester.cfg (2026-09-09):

# AndroidTester Klipper config — BIGTREETECH SKR Pico v1.0 (RP2040 over USB).
#
# CoreXY gantry (stepper_x/stepper_y) + tool-Z elevator as a manual_stepper
# (auxiliary axis, not part of the CoreXY kinematics) + three hobby servos
# (two nest button plungers, one finger deploy/stow). Design docs:
# docs/01-mechanical.md, docs/02-electronics.md (pin map, power, E-stop).
#
# This file defines the macro contract the Python framework calls (see
# androidtester/harness.py); tests/test_macro_contract.py fails if the two
# drift apart. Straight-line moves only, no math.* in templates (Klipper's
# Jinja context lacks it). Calibrate rotation_distance/endstop polarity on
# the real machine.
#
# Flash the RP2040 with USB communication; get the serial path from
# `ls /dev/serial/by-id/` after the first boot.

[mcu]
serial: /dev/serial/by-id/usb-Klipper_rp2040_CHANGE_ME
restart_method: command

[printer]
kinematics: corexy
max_velocity: 200
max_accel: 1500
# No max_z_velocity/max_z_accel: the real tool-Z is [manual_stepper tool_z]
# below; the placeholder Z rail never moves.

# Klipper's corexy kinematics loads three rails (x/y/z) unconditionally, so a
# placeholder stepper_z must exist even though this rig has no G-code Z axis.
# It sits on otherwise-unused pins (E0 enable, filament-sensor port, probe
# port, THB input), is NEVER homed (HOME_ALL does G28 X Y only) and never
# moved — the tool elevator is driven exclusively via MANUAL_STEPPER so no
# G-code path can move Z. Nothing is attached to these pins.
[stepper_z]
step_pin: gpio16                    # FSC port (free)
dir_pin: gpio22                     # PROBE port (free)
enable_pin: !gpio15                 # E0 socket EN (socket empty)
microsteps: 16
rotation_distance: 8
endstop_pin: ^gpio26                # THB input, usable as digital-in
position_min: 0
position_max: 60
position_endstop: 0
homing_speed: 5

# -- motion: CoreXY A/B ---------------------------------------------------------
# rotation_distance 40 = GT2 belt (2.0 mm pitch) x 20-tooth pulley = 40.0 mm/rev.

[stepper_x]
step_pin: gpio11
dir_pin: gpio10
enable_pin: !gpio12
microsteps: 16
rotation_distance: 40               # 2.0 mm pitch x 20 T pulley
endstop_pin: ^gpio4                 # X-STOP port, microswitch to GND
position_endstop: 0
position_max: 400                   # == config.py deck_width_mm
homing_speed: 40

[tmc2209 stepper_x]
uart_pin: gpio9
tx_pin: gpio8
uart_address: 0                     # MS jumper block: X socket = address 0
sense_resistor: 0.110
run_current: 0.8
stealthchop_threshold: 999999

[stepper_y]
step_pin: gpio6
dir_pin: gpio5
enable_pin: !gpio7
microsteps: 16
rotation_distance: 40               # 2.0 mm pitch x 20 T pulley
endstop_pin: ^gpio3                 # Y-STOP port, microswitch to GND
position_endstop: 0
position_max: 300                   # == config.py deck_height_mm
homing_speed: 40

[tmc2209 stepper_y]
uart_pin: gpio9
tx_pin: gpio8
uart_address: 2                     # MS jumper block: Y socket = address 2
sense_resistor: 0.110
run_current: 0.8
stealthchop_threshold: 999999

# -- tool-Z elevator (finger height) --------------------------------------------
# NEMA17 + T8 lead screw: rotation_distance 8 = 2 mm pitch x 4 starts = 8 mm/rev.
# Homes UP against a microswitch at the top of travel (away from the deck) via
# MANUAL_STEPPER ... STOP_ON_ENDSTOP=home, then SET_POSITION fixes the frame.
# NOTE: no position_min/position_max here on purpose — the homing move targets
# past the switch and would be range-rejected. The macros only ever command
# 0..Z_TOP.

[manual_stepper tool_z]
step_pin: gpio19
dir_pin: gpio28
enable_pin: !gpio2
microsteps: 16
rotation_distance: 8                # T8x8 lead screw
velocity: 30
accel: 200
endstop_pin: ^gpio25                # Z-STOP port, switch at the TOP of travel

[tmc2209 manual_stepper tool_z]
uart_pin: gpio9
tx_pin: gpio8
uart_address: 1                     # MS jumper block: Z socket = address 1
sense_resistor: 0.110
run_current: 0.6                    # lead screw only lifts the ~150 g tool
stealthchop_threshold: 999999

# -- servos ----------------------------------------------------------------------
# plunger_0/plunger_1 are the contract names devices/*.yaml map buttons to.
# finger_deploy swings the finger tool between stow and working positions.
# The E0 driver socket stays EMPTY: its STEP/DIR pins are repurposed as the
# two extra servo signals (RP2040 PWM works on any GPIO). Servo 5 V/GND comes
# from the servo buck, not the board — see docs/02-electronics.md.

[servo plunger_0]                   # e.g. power button
pin: gpio29                         # SERVO port
maximum_servo_angle: 180
minimum_pulse_width: 0.0005
maximum_pulse_width: 0.0025

[servo plunger_1]                   # e.g. volume buttons
pin: gpio14                         # E0 socket STEP pin (socket unused)
maximum_servo_angle: 180
minimum_pulse_width: 0.0005
maximum_pulse_width: 0.0025

[servo finger_deploy]               # finger tool stow/deploy
pin: gpio13                         # E0 socket DIR pin (socket unused)
maximum_servo_angle: 180
minimum_pulse_width: 0.0005
maximum_pulse_width: 0.0025

# -- machine constants (calibrate per rig) --------------------------------------
# travel_z/touch_z mirror config.py travel_z_mm/touch_z_mm (checked by
# tests/test_design_package.py).

[gcode_macro _AT_VARS]
description: AndroidTester machine constants
variable_travel_z: 40.0           # clearance plane: no XY travel below this
variable_touch_z: 5.0             # finger-tip contact height
variable_z_top: 60.0              # tool-Z travel limit (top endstop position)
variable_park_x: 10.0
variable_park_y: 10.0
variable_travel_speed: 150.0      # mm/s (XY)
variable_z_speed: 30.0            # mm/s (tool-Z)
variable_z_touch_speed: 10.0      # mm/s (tool-Z approach to the glass)
variable_plunger_rest_angle: 10
variable_plunger_press_angle: 80
variable_finger_deploy_angle: 90  # working position (finger vertical)
variable_finger_stow_angle: 0     # swung clear of the nest
gcode:                            # variables only; never called directly

# -- macro contract: called by androidtester/harness.py --------------------------
# Every FINGER_* macro returns tool-Z to travel_z; HOME_ALL re-zeros the frame,
# so the absolute MANUAL_STEPPER moves below never drift.

[gcode_macro HOME_ALL]
description: Home X, Y, and tool-Z
gcode:
    {% set v = printer["gcode_macro _AT_VARS"] %}
    G90
    G28 X Y
    # tool-Z: drive past the top switch, stop on trigger, then define position
    MANUAL_STEPPER STEPPER=tool_z SET_POSITION=0
    MANUAL_STEPPER STEPPER=tool_z MOVE={v.z_top + 5} STOP_ON_ENDSTOP=home SPEED={v.z_touch_speed}
    MANUAL_STEPPER STEPPER=tool_z SET_POSITION={v.z_top}
    MANUAL_STEPPER STEPPER=tool_z MOVE={v.travel_z} SPEED={v.z_speed}

[gcode_macro TOOLS_UP]
description: Lift the toolhead to the travel clearance plane
gcode:
    {% set v = printer["gcode_macro _AT_VARS"] %}
    G90
    MANUAL_STEPPER STEPPER=tool_z MOVE={v.travel_z} SPEED={v.z_speed}

[gcode_macro FINGER_TAP]
description: Tap at X, Y (deck mm); tools up first, down only for the touch
gcode:
    {% set v = printer["gcode_macro _AT_VARS"] %}
    {% set x = params.X|float %}
    {% set y = params.Y|float %}
    G90
    SET_SERVO SERVO=finger_deploy ANGLE={v.finger_deploy_angle}
    MANUAL_STEPPER STEPPER=tool_z MOVE={v.travel_z} SPEED={v.z_speed}
    G1 X{x} Y{y} F{v.travel_speed * 60}
    MANUAL_STEPPER STEPPER=tool_z MOVE={v.touch_z} SPEED={v.z_touch_speed}
    G4 P80
    MANUAL_STEPPER STEPPER=tool_z MOVE={v.travel_z} SPEED={v.z_speed}

[gcode_macro FINGER_SWIPE]
description: Swipe from (X1, Y1) to (X2, Y2) over T milliseconds
gcode:
    {% set v = printer["gcode_macro _AT_VARS"] %}
    {% set x1 = params.X1|float %}
    {% set y1 = params.Y1|float %}
    {% set x2 = params.X2|float %}
    {% set y2 = params.Y2|float %}
    {% set t_ms = [params.T|default(400)|int, 50]|max %}   # clamp: no div-by-zero
    # Feed from the dominant axis (straight-line only, no trig): diagonal
    # swipes run up to sqrt(2)x slower than requested — acceptable for UI.
    # Feed clamped to 300..9000 mm/min (5..150 mm/s).
    {% set dist = [(x2 - x1)|abs, (y2 - y1)|abs]|max %}
    {% set feed = [[60.0 * dist * 1000.0 / t_ms, 300]|max, 9000]|min|int %}
    G90
    SET_SERVO SERVO=finger_deploy ANGLE={v.finger_deploy_angle}
    MANUAL_STEPPER STEPPER=tool_z MOVE={v.travel_z} SPEED={v.z_speed}
    G1 X{x1} Y{y1} F{v.travel_speed * 60}
    MANUAL_STEPPER STEPPER=tool_z MOVE={v.touch_z} SPEED={v.z_touch_speed}
    G1 X{x2} Y{y2} F{feed}
    MANUAL_STEPPER STEPPER=tool_z MOVE={v.travel_z} SPEED={v.z_speed}
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

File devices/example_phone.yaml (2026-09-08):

# Generic ~6.1" slab phone, lying face-up in the nest, home button edge down.
# All coordinates are deck millimetres from the gantry origin; launcher/pin-pad
# points are screen-relative fractions (0..1, origin top-left of the screen).
name: example_phone
class: phone

body:
  width_mm: 71.5
  height_mm: 147.0
  thickness_mm: 8.9

# Screen corners TL, TR, BR, BL in deck mm (device nest origin at [60, 80]).
screen_polygon:
  - [63.0, 84.0]
  - [128.5, 84.0]
  - [128.5, 221.0]
  - [63.0, 221.0]

buttons:
  power:
    position: [134.5, 130.0, 10.0]
    plunger: plunger_0
  volume_up:
    position: [134.5, 110.0, 10.0]
    plunger: plunger_1
  volume_down:
    position: [134.5, 95.0, 10.0]
    plunger: plunger_1

launcher:
  settings: {x: 0.25, y: 0.40}
  camera: {x: 0.75, y: 0.40}
  # Lock-screen PIN pad, standard 3x4 grid.
  pin_1: {x: 0.25, y: 0.45}
  pin_2: {x: 0.50, y: 0.45}
  pin_3: {x: 0.75, y: 0.45}
  pin_4: {x: 0.25, y: 0.58}
  pin_5: {x: 0.50, y: 0.58}
  pin_6: {x: 0.75, y: 0.58}
  pin_7: {x: 0.25, y: 0.71}
  pin_8: {x: 0.50, y: 0.71}
  pin_9: {x: 0.75, y: 0.71}
  pin_0: {x: 0.50, y: 0.84}

quirks:
  key_settle_s: 0.15        # pause between PIN digit taps
  screen_on_settle_s: 1.5   # display wake latency after power press

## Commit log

2026-09-08 Initial commit: project scaffold
    Open-hardware robot that physically tests Android phones: CoreXY gantry,
    conductive-tip finger, NFC card manipulator, camera/OCR verification.
    Fully black-box — a scenario must pass with the USB port unplugged.
2026-09-08 Scope: target phones and tablets; touch/buttons/camera only
    Drop NFC/card-manipulator content — AndroidTester is the starting point
    of the family: modular toolhead, finger first.
2026-09-08 M1: framework skeleton
    Moonraker motion client behind a MotionClient Protocol (strict
    wait_idle), harness ops with tools-up choreography and park-on-failure,
    device profiles (phone/tablet), vision (rectify, template image/OCR
    fallback behind a pluggable backend), YAML scenario runner with
    pre/steps/post, per-step timeouts, JSON+JUnit reports, dry-run mode.
    Klipper macro contract in firmware/klipper/androidtester.cfg with a
    drift-guard test. Example devices + three scenarios. 55 tests green.
    [androidtester.cfg]
2026-09-09 M2: camera deck registration
    ArUco marker detection (opencv 4.x/5.x tolerant) + normalized DLT
    homography px<->deck-mm with RMS gating (0.228 mm on synthetic frames);
    OverheadCamera Protocol with OpenCV and Synthetic (pinhole-projected)
    implementations; camera.calibrate scenario step; touch targets as
    screen fractions; calibration RMS recorded in report.json; calib CLI
    with annotated frames. 80 tests green.
2026-09-09 M4: twin parity — framework runs against the Steropes physics twin
    harness.twin.yaml points the unmodified stack (real MoonrakerClient,
    OpenCVCamera over MJPEG, calibration, OCR) at a running Steropes server.
    Env-gated integration tests (STEROPES_ROOT): cross-repo macro drift
    guard and a full smoke_wake_unlock run against a spawned twin.
    README: twin quickstart, M4 done. 80 ungated + 2 gated tests green.
2026-09-09 M0: machine design package
    Parametric OpenSCAD parts (frame brackets, gantry carriage, finger
    module, button plunger, adjustable device nest, camera mounts) with
    PART-selector convention + rendered previews; docs: mechanical (rail
    arithmetic shown, tap force budget), electronics (SKR Pico pin map,
    E-stop as power-cut), BOM (row-sum test-pinned, ~418 EUR). Firmware
    cfg fleshed out for the board with the macro contract unchanged;
    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
    [00_config.scad, androidtester.cfg, belt_clamp.stl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]
